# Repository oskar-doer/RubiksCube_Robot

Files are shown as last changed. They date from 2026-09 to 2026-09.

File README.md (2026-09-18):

# Rubik's Cube Robot

This robot solves a Rubik's Cube automatically. An ESP32-S3 reads the state of
a QiYi QYSC-S Rubiks Cube via Bluetooth and calculates a solution using the min2phase
algorithm. A FYSETC F6 then controls six stepper motors that turn the cube.

## Demo

Current record: **0.902 s**

<div align="center">

https://github.com/user-attachments/assets/f63d3622-d1c3-4cb1-b660-a3a5f470cd66

</div>

## Features

- Cube state detection via Bluetooth
- Solution calculation directly on the ESP32-S3
- Six individually controlled NEMA 17 stepper motors
- Parallel movement of opposite cube faces
- Status, progress, and time display on an LCD1602
- Ability to abort an ongoing movement
- Individual tests for motors, TMC UART, and the connection between both controllers

## How It Works

1. The ESP32-S3 connects to the QiYi cube via Bluetooth.
2. The current cube state is read and verified.
3. The min2phase solver calculates and evaluates suitable move sequences.
4. The ESP32 sends the selected move sequence to the FYSETC F6 via UART.
5. The F6 generates the STEP/DIR signals for the six TMC2209 motor drivers.
6. After the movement, the ESP32 verifies the cube's new state.

## Hardware

The build consists of an ESP32-S3, a FYSETC F6, six TMC2209 motor drivers,
six NEMA 17 stepper motors, an LCD1602, and a QiYi QYSC-S. The complete list is
available in the [component list](docs/HARDWARE.md).

| Robot | Control electronics |
|:---:|:---:|
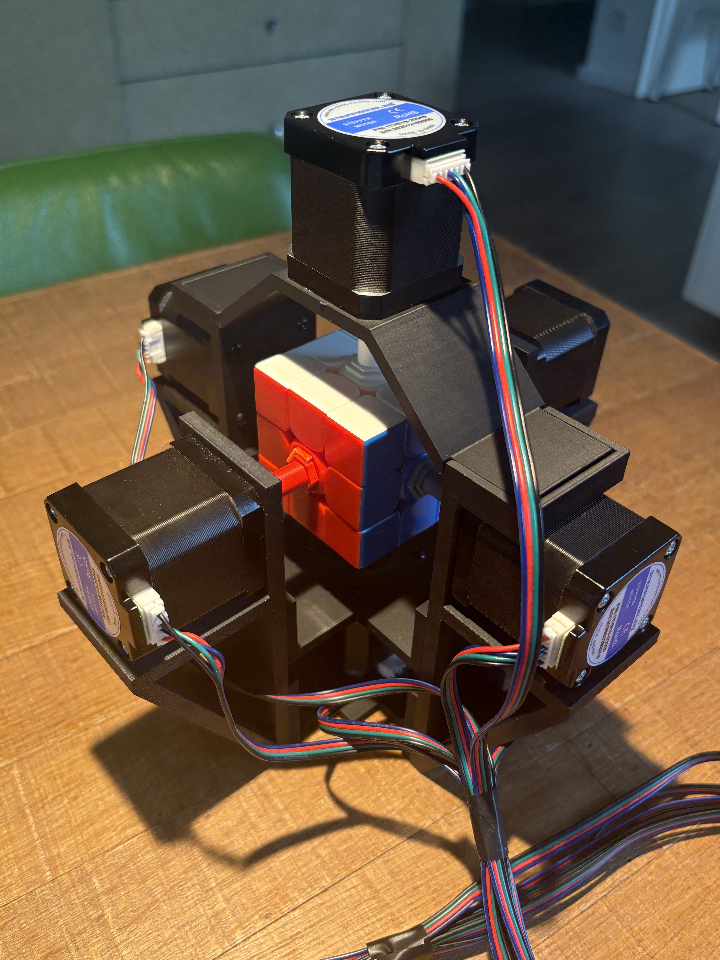
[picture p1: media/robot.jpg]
Mechanical structure of the robot
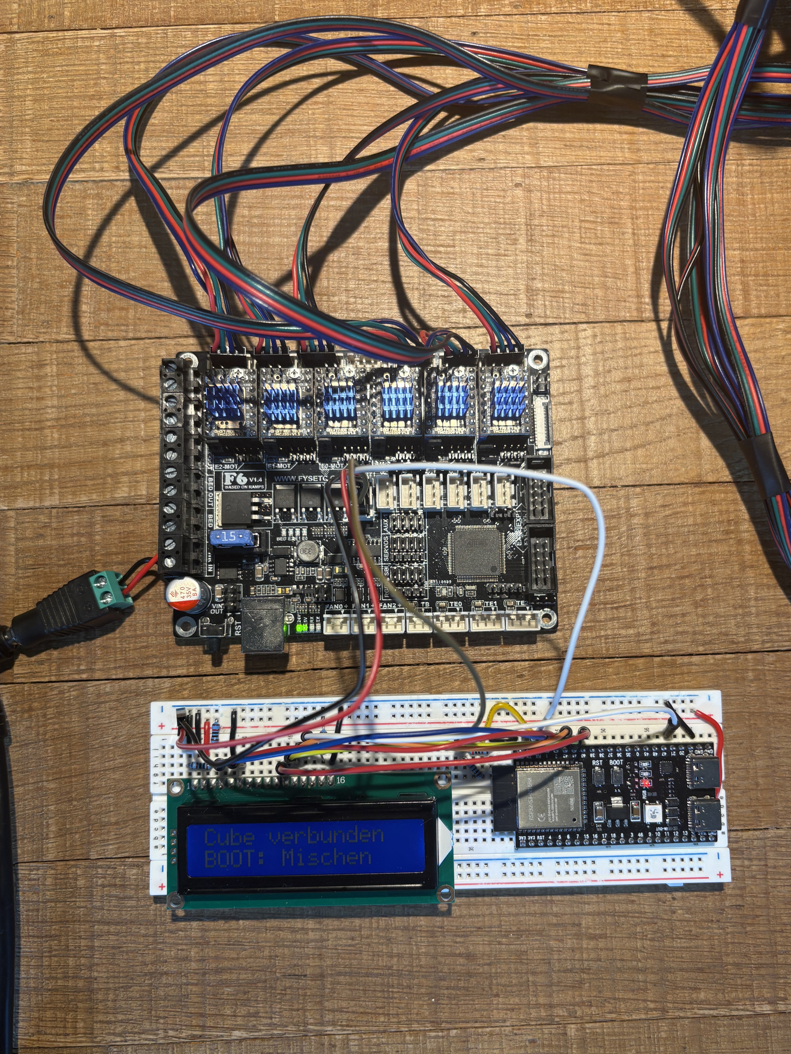
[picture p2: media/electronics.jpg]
FYSETC F6, ESP32-S3, and LCD1602
|  |  |

## Software

The firmware consists of two programs:

- [`esp32_cube_controller`](Code/robot/esp32_cube_controller/): Bluetooth,
  state verification, solver, LCD, and communication with the F6
- [`f6_motion_controller`](Code/robot/f6_motion_controller/): motor driver
  configuration and execution of the calculated cube moves

The complete connections are described in the
[wiring instructions](Code/robot/WIRING.md). Operation and configured motion
values are covered by the [robot documentation](Code/robot/README.md).

## Building the Robot

1. Print the parts in [`3D Model`](3D%20Model/).
2. Mechanically assemble the motors, adapters, frame, and cube.
3. Connect the ESP32-S3, LCD1602, FYSETC F6, and motor drivers according to the
   [wiring instructions](Code/robot/WIRING.md).
4. First, test the individual components with the programs in
   [`Code/tests`](Code/tests/).
5. Then upload the two programs in [`Code/robot`](Code/robot/).

The Arduino settings and upload instructions are provided in the README files
of the respective firmware directories.

## Tests

[`Code/tests`](Code/tests/) contains separate programs for:

- the UART connection to a TMC2209
- moving a single motor
- the UART connection between the ESP32-S3 and FYSETC F6
- checking the direction of rotation of all six motors

## Project Structure

```text
Code/
  robot/    Production firmware for ESP32-S3 and FYSETC F6
  tests/    Programs for commissioning and troubleshooting
docs/       Component list
3D Model/   Print-ready STL files
```

## Notes

- Only connect or disconnect motors and motor drivers when the 24 V supply is
  switched off.
- Check the driver orientation and current limit before switching on the power.
- The F6's 5 V TX output may only be connected to the ESP32's 3.3 V RX input
  through the [documented voltage divider](Code/robot/WIRING.md#esp32-s3-to-fysetc-f6).
- License notices for the solver and QiYi protocol are included with the
  ESP32 firmware.

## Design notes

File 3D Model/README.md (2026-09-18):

# 3D-Printed Parts

All STL files in this directory are original parts designed and created by the author of this project. They are not derived from third-party CAD models.

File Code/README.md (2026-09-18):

# Rubik's Cube Robot

This repository separates the production robot firmware from standalone
hardware tests:

```text
robot/
  esp32_cube_controller/   Production ESP32-S3 firmware
  f6_motion_controller/    Production FYSETC F6 firmware
tests/                     Individual tests for setup and troubleshooting
```

For normal operation, upload these two sketches:

- `robot/esp32_cube_controller/esp32_cube_controller.ino`
- `robot/f6_motion_controller/f6_motion_controller.ino`

The production UART connection between the ESP and F6 uses 250000 baud. The
USB monitors use 115200 baud. Sketches under `tests/` are independent diagnostic
programs and can therefore use different settings, particularly 115200 baud
between the test devices.

The complete production wiring is documented in
[`robot/WIRING.md`](robot/WIRING.md). Operation and the currently configured
motion values are documented in [`robot/README.md`](robot/README.md). Details
about the two controllers are provided in their respective subdirectories.

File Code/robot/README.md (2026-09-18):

# Rubik's Cube Robot Control

## Programs

- `esp32_cube_controller`: reads the QiYi cube via Bluetooth, calculates a
  solution with min2phase, displays the state on the LCD, and sends the move
  sequence to the F6 via UART.
- `f6_motion_controller`: receives the move sequence, generates STEP/DIR signals
  for the six TMC2209 drivers, and reports progress and measured movement time.

The F6 executes directly consecutive moves of opposite faces in parallel: U
with D, R with L, and F with B. The remaining sequence stays unchanged.

The motor assignment, direction of rotation, and steps per 90 degrees have been
verified. Motor movement is enabled in the F6 program with
`MOTION_CONFIGURATION_CONFIRMED=true`.

The complete connections for the power supply, LCD, controllers, motor drivers,
and motors are documented in [WIRING.md](WIRING.md).

## Operation

After a valid cube connection, the LCD displays `Cube verbunden` ("Cube
connected"). Briefly
pressing the ESP's BOOT button (GPIO0) solves a scrambled cube. If the Bluetooth
cube is already solved, the same button starts a random 20-move scramble.
Pressing it again during the motor run aborts the movement. The serial command
`s` starts the same state-dependent action; `x` aborts it.
As soon as the F6 reports `START`, the LCD shows the elapsed time and move
progress. After `DONE`, the ESP confirms success exclusively based on the state
subsequently reported by the Bluetooth cube. `x` aborts an ongoing motor
sequence.

After a confirmed solution, the LCD displays the motor time alone and the move
count. The USB monitor additionally shows the solver, motor, and total times.
The solver keeps the first result as a fallback and continues searching for a
total of three seconds for the fastest sequence with no more than 30 moves.
Directly consecutive moves of opposite faces count together as one time step
that can be executed in parallel.

The BOOT button may only be pressed after power-up or reset. If it is held
during a reset, the ESP starts in download mode. The RST button remains the
reset button.

## Measured Motion Values

- Reference measurement at 16 microsteps: 400 pulses produce approximately 45 degrees.
- Reference measurement at 16 microsteps: 800 pulses therefore produce 90 degrees.
- In the production profile with 2 microsteps, 100 pulses therefore correspond
  to a 90-degree turn.
- `+`, or DIR HIGH, turns counterclockwise when looking at the motor from the
  front. This means viewing it from the shaft/adapter side.
- Because the shaft/adapter side faces the cube, DIR HIGH corresponds to a
  clockwise move when looking at the respective colored cube face from the outside.

## Setting Speed and Motor Current

The clearly visible settings are at the beginning of
`f6_motion_controller.ino` in the `EINFACHE BEWEGUNGSEINSTELLUNGEN` ("simple
motion settings") block:

- `STEPS_PER_90_DEGREES = 100`: pulses for 90 degrees at 2 microsteps
- `START_SPEED_DEG_PER_SEC = 500`: speed at the beginning/end of a turn
- `MAX_SPEED_DEG_PER_SEC = 2400`: peak speed for 90-degree moves
- `MAX_SPEED_180_DEG_PER_SEC = 2600`: peak speed for 180-degree moves
- `ACCELERATION_STEPS = 8`: ramp for 90-degree moves
- `ACCELERATION_180_STEPS = 14`: longer ramp for 180-degree moves
- `MOTOR_RMS_CURRENT_MA = 1700`: running current per motor; 1700 corresponds to 1.7 A RMS
- `MOTOR_HOLD_MULTIPLIER = 0.35`: holding current for stationary motors
- `DRIVER_MICROSTEPS = 2`: microsteps configured via UART with interpolation
- `USE_SPREADCYCLE = true`: more torque during fast movements

The STEP pulses are generated by Timer1 at absolute times. As a result, serial
responses and emergency-stop polling do not change the motor speed. Opposite
faces continue to move simultaneously; individual speeds for each motor are
intentionally not used.

At startup, the F6 configures all six TMC2209 drivers via UART and checks
`test_connection = 0` and `VERSION = 0x21` for each one. If any driver does not
respond, all motor commands remain disabled and the ESP receives `DRIVER_UART`.

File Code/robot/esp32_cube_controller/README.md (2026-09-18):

# ESP32-S3 Cube Controller

This is the robot's production ESP32-S3 firmware. It connects to the QiYi
QYSC-S via Bluetooth, reads and verifies the cube state, calculates a solution,
displays the process on the LCD1602, and sends the move sequence to the FYSETC
F6 via UART.

## Uploading with the Arduino IDE

Keep the entire directory together and open `esp32_cube_controller.ino` in the
Arduino IDE.

Settings used:

| Setting | Value |
|---|---|
| Board package | esp32 by Espressif Systems 3.3.11 |
| Board | ESP32S3 Dev Module |
| CPU Frequency | 240 MHz |
| Flash Size | 16 MB (128 Mb) |
| PSRAM | OPI PSRAM |
| USB CDC On Boot | Enabled when using the native USB connector |
| USB Mode | Hardware CDC and JTAG |
| Partition Scheme | Custom (`partitions.csv`) |
| Serial monitor | 115200 baud |

When using the UART USB connector, `USB CDC On Boot` must be disabled. If the
upload does not start, hold BOOT, briefly press RESET, release BOOT, and upload
again.

On the first startup, min2phase generates its search tables in PSRAM and saves
them to LittleFS. This can take several minutes. Later startups load the
appropriate cache from flash memory.

## Wiring

The LCD1602 pinout, ESP-to-F6 UART connection, voltage divider, power wiring,
driver setup, and motor connections are documented centrally in
[WIRING.md](../WIRING.md).

## Operation

- Briefly press BOOT: solve a scrambled cube; scramble a solved cube with 20 moves
- Hold BOOT for three seconds: calibrate a physically solved cube as solved
- Press BOOT during a motor run: send an emergency stop to the F6

| Serial command | Function |
|---|---|
| `s` | Solve or scramble depending on the cube state |
| `c` | Calibrate a solved cube |
| `x` | Abort the motor run |
| `p` | Display the cube state and battery level |
| `t` | Test the solver with a virtual test cube |
| `l` | Display an LCD test pattern |
| `w` | Measure the LCD lines individually |
| `r` | Reestablish the Bluetooth connection |
| `h` or `?` | Display help |

The solver runs in a separate task so that Bluetooth and the display continue
to operate during the search. The cube must not be turned during the
calculation; any solution rendered outdated as a result is discarded.

## Solution Selection

The first valid solution is retained as a fallback. The ESP then continues
searching for a total of three seconds and evaluates every variant found by the
number of motor time steps:

- A normal move counts as one time step.
- Consecutive moves of opposite faces (`U D`, `R L`, `F B`, and vice versa)
  count together as one time step because the F6 executes them simultaneously.
- If the number of time steps is equal, the sequence with fewer individual moves wins.

The selected sequence may contain no more than 30 individual moves. Each answer
is replayed using an independent cube model before it is sent to the F6. The
evaluation selects the best variant found within the search window; it does not
prove a global optimum.

## Feedback and Errors

During the motor run, the LCD shows progress and elapsed time. After the run,
the ESP verifies the new Bluetooth state. Even if the solution fails, the motor
time reported by the F6 remains visible. On success, the LCD displays the motor
time and move count; the USB monitor outputs the solver, motor, and total times.

- `F6 nicht bereit` ("F6 not ready"): check the UART connection, common ground, and both baud rates.
- `TMC-UART Fehler` ("TMC UART error"): check the drivers named on the LCD and their jumpers.
- `PSRAM 0 MB`: check OPI PSRAM, the board selection, and the N16R8 module.
- No cube: wake the cube and disconnect it from other apps.
- Invalid state: calibrate the cube in the manufacturer's app or use `c` here.

## File Structure

- `esp32_cube_controller.ino`: Arduino entry point
- `app.cpp`: Bluetooth, LCD, operation, and F6 communication
- `qiyi_protocol.h`: QiYi frames, CRC, and state decoding
- `solver_adapter.cpp/.h`: min2phase integration and preparation
- `cube_model.c/.h`: independent state and solution verification
- `src/min2phase/`: adapted solver library

## Sources and Licenses

- [min2phaseCXX](https://github.com/lilborgo/min2phaseCXX): `src/min2phase/UPSTREAM-LICENSE.md`
- [QiYi protocol documentation](https://codeberg.org/Flying-Toast/qiyi_smartcube_protocol) by Simon Schwartz (MIT): `LICENSE-qiyi.txt`
- Independent cube model and integration software (GPL-3.0-or-later): `LICENSE-GPL-3.0.txt`

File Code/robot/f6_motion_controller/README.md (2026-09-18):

# F6 Motion Controller

Arduino board profile: `FYSETC F6 V1.4`, library: `TMCStepper`, serial
monitor: 115200 baud. The UART connection to the ESP on `Serial1` operates at
250000 baud.

The controller UART, TMC2209 setup, and motor connections are documented in
[WIRING.md](../WIRING.md).

The controller understands solutions consisting of `U R F D L B` and the
suffixes `'` and `2`. Example from the ESP:

```text
RUN 1 U R' F2 D
```

Responses:

```text
READY
PONG
START 1 4
MOVE 1 1 4
DONE 1 1234
ERR 1 FEHLERNAME
```

`!` aborts a movement. You can also enter `x` in the F6's USB serial monitor
for this purpose.

Timer1 generates the STEP edges at absolute times. The motion profile uses 2
microsteps with TMC interpolation, separate ramps for 90- and 180-degree moves,
and continues to execute moves of opposite faces in parallel.

The six entries in `motors[]`, their directions of rotation, and
`MOTION_CONFIGURATION_CONFIRMED=true` correspond to the verified setup. They
only need to be changed if the motors or slots are rearranged.

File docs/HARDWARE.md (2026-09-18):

# Hardware Components

The connections between these components are documented in the
[robot wiring instructions](../Code/robot/WIRING.md).

* 1x ESP32-S3-WROOM-1-N16R8 module from Espressif Systems
* 1x F6 V1.4 control board from FYSETC
* 6x TMC2209 V1.3 motor drivers from BIGTREETECH
  * On these modules, the R10 solder bridge on the `PDN_UART` signal had to be
    closed for UART operation. Other TMC2209 StepStick variants with `PDN_UART`
    already configured or exposed appropriately may simplify the build. Before
    purchasing, verify the pin assignment and UART connection against the
    FYSETC F6 V1.4.
* Heat sinks for the TMC2209 motor drivers
* 6x 17HE19-2004S NEMA 17 stepper motors from StepperOnline
* 1x power supply, 24 V DC / 8 A
* 1x LCD1602 display module
* 1x QYSC-S Bluetooth cube from QiYi
* 1x 10 kOhm, 3x 1 kOhm, and 1x 2 kOhm resistors (0.25 W is sufficient):
  10 kOhm/1 kOhm for the LCD contrast divider, 1 kOhm for the LCD backlight,
  and 1 kOhm/2 kOhm for the F6-to-ESP UART level divider
* Small electronic components and connection cables
* M3 threaded insert and M3 screws

## Documentation

* [ESP32-S3-WROOM-1 datasheet from Espressif](https://www.espressif.com/sites/default/files/documentation/esp32-s3-wroom-1_wroom-1u_datasheet_en.pdf)
* [FYSETC F6 documentation, schematic, and board files](https://github.com/FYSETC/FYSETC-F6)
* [General TMC2209 documentation from BIGTREETECH](https://github.com/bigtreetech/docs/blob/master/docs/TMC2209.md)
* [Product information and datasheet for the StepperOnline 17HE19-2004S](https://www.omc-stepperonline.com/e-series-nema-17-bipolar-55ncm-77-88oz-in-2a-42x48mm-4-wires-w-1m-cable-connector-17he19-2004s)

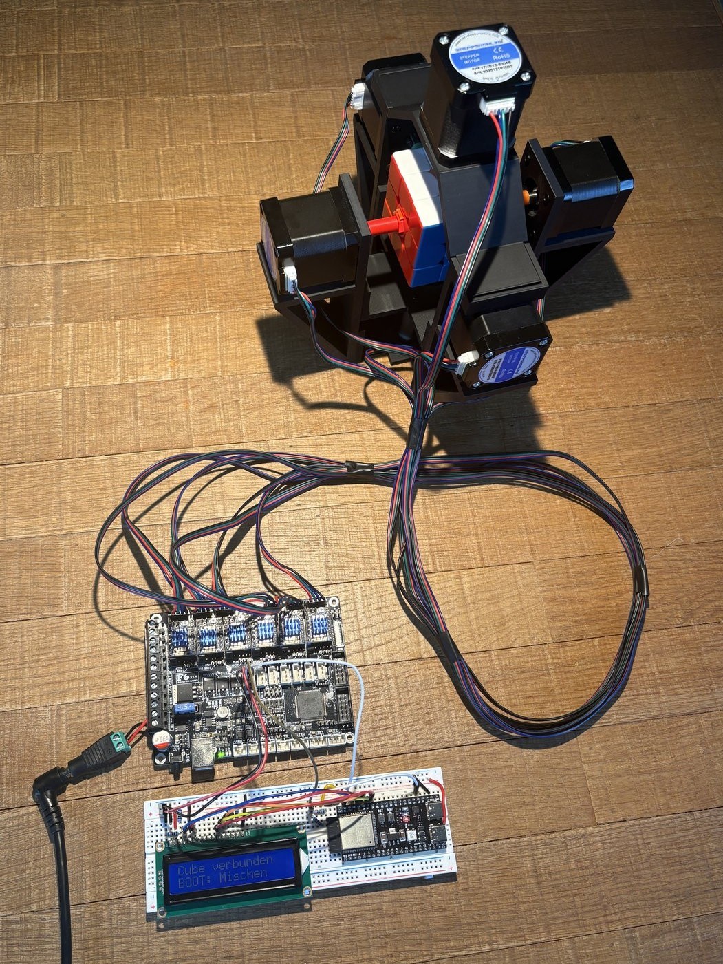
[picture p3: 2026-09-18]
media/robot-and-electronics.jpg

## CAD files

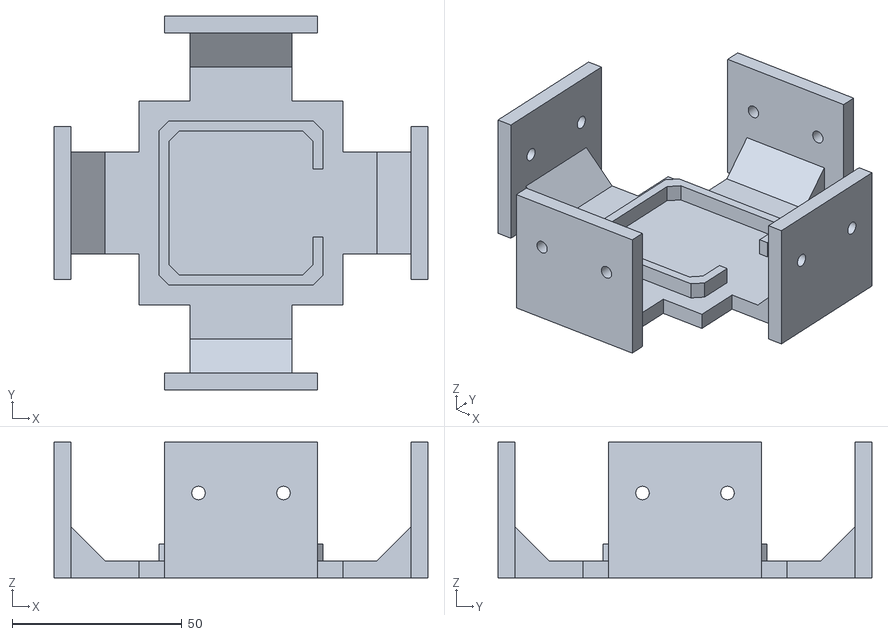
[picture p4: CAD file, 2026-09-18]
3D Model/Bodenplatte.STL
110.0 x 110.0 x 40.0

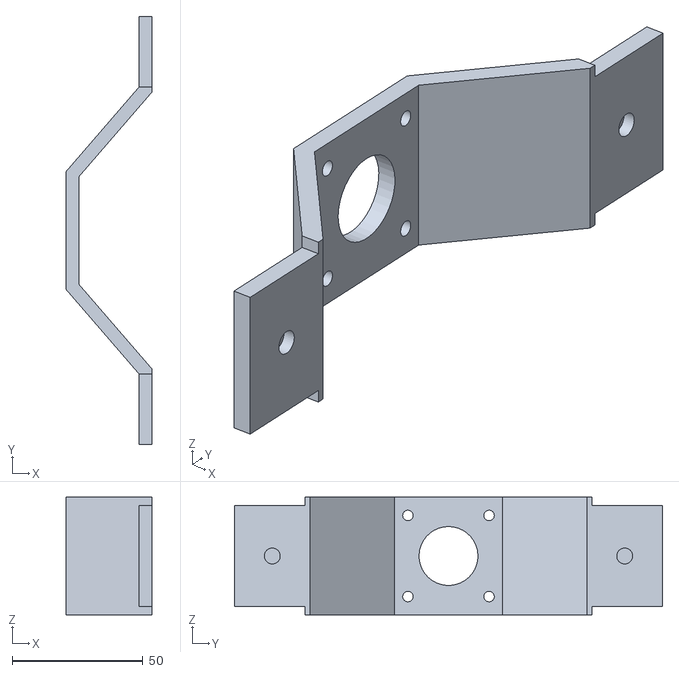
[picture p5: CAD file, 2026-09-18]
3D Model/Platte oben.STL
32.8 x 163.5 x 45.0

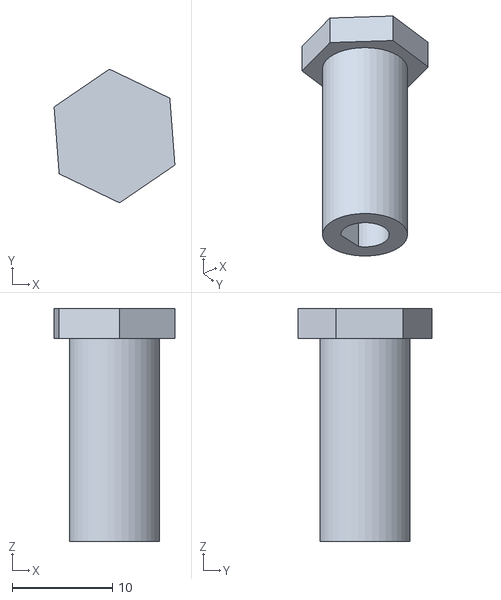
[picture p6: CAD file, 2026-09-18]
3D Model/adapter oben_unten.STL
12.1 x 13.4 x 23.3

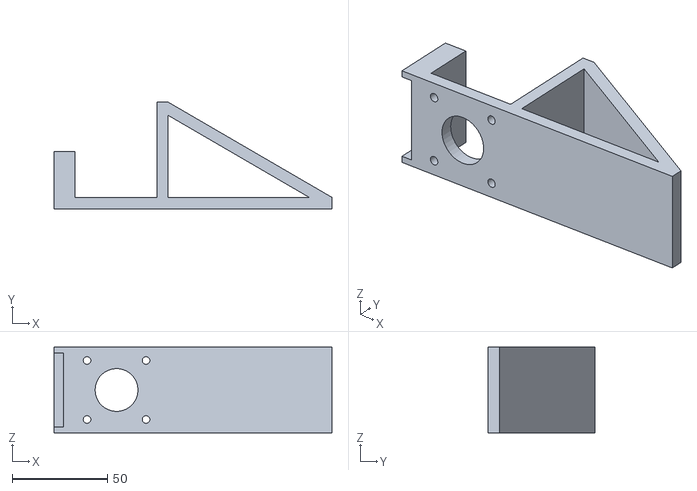
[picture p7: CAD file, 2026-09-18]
3D Model/Seiten platte - mit halter.STL
146.0 x 56.0 x 45.0

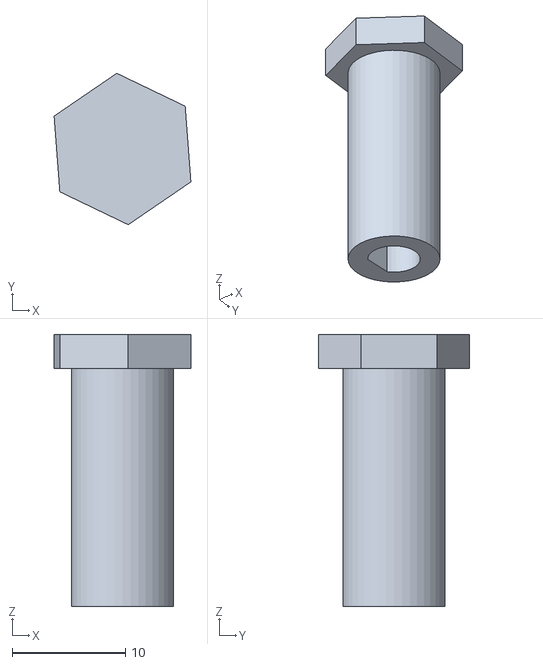
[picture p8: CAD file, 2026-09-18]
3D Model/adapter seite.STL
12.1 x 13.4 x 24.0

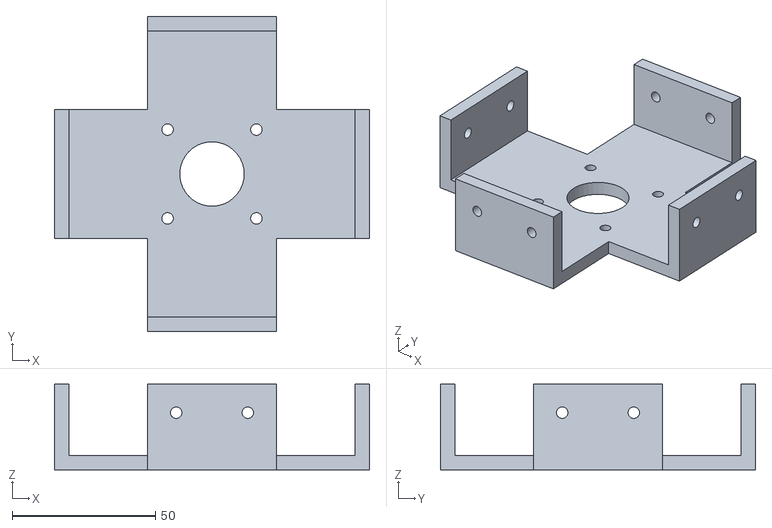
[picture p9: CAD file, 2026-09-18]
3D Model/unterer Motor halter.STL
110.0 x 110.0 x 30.0

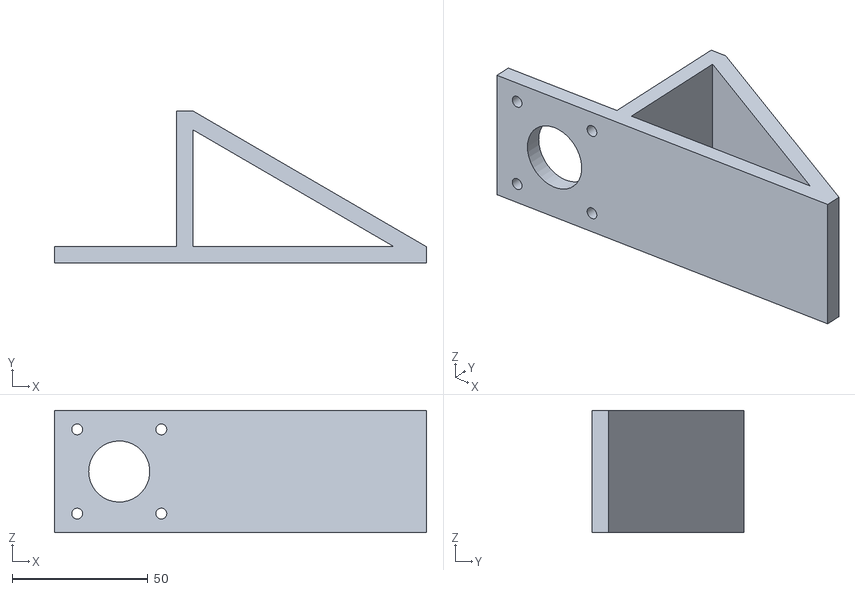
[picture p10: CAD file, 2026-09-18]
3D Model/Seiten platte.STL
137.0 x 56.0 x 45.0

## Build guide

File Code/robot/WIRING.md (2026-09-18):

# Wiring Instructions

This document contains the complete wiring for the production robot. The test
sketches under `../tests/` may use different baud rates, but they use the same
physical ESP32-S3, F6, driver, and motor connections described here.

## Safety

- Switch off and disconnect the 24 V supply before installing or removing a
  TMC2209 driver or motor cable.
- Check the polarity of every supply connection before switching on power.
- Never connect the F6's 24 V motor supply to the ESP32-S3 or LCD.
- Connect the ESP32-S3 and LCD only to the F6's regulated 5 V output, never to
  its 24 V input.
- Fit a heat sink to every TMC2209 and check each driver's orientation before
  powering the F6.
- The F6 and ESP32-S3 must share GND.
- The F6 TX1 signal is 5 V. Connect it to the ESP32-S3 only through the voltage
  divider shown below.

## Power

1. Connect the 24 V DC / 8 A supply to the main power input of the FYSETC F6,
   observing the marked positive and negative terminals.
2. Connect a regulated `5V` output on the F6 directly to the ESP32-S3's
   `5V`/`5Vin` input. Connect F6 GND directly to ESP32-S3 GND.
3. Connect the same F6 `5V` rail directly to LCD pin 2 (`VDD`) and the F6 GND
   rail directly to LCD pin 1 (`VSS`). For the contrast voltage, connect a
   10 kOhm resistor from F6 `5V` to LCD pin 3 (`VO`) and a 1 kOhm resistor from
   LCD pin 3 (`VO`) to F6 GND. The LCD is not powered through the ESP.
4. Connect LCD pin 15 (`A`/`LED+`) to F6 `5V` through a 1 kOhm resistor and
   connect LCD pin 16 (`K`/`LED-`) directly to F6 GND.
5. The UART connection uses this same common GND.

The ESP32-S3 and LCD are two parallel loads on the F6's 5 V rail: both receive
their 5 V directly from the F6. Do not feed either device from the F6's 24 V
input. When connecting USB to the ESP32-S3 for programming, avoid connecting
two 5 V sources unless the specific ESP32-S3 development board explicitly
supports it.

Do not switch on the 24 V supply until the drivers, motor cables, controller
UART, and common ground have all been checked.

## ESP32-S3 to LCD1602

The LCD is connected directly in 4-bit mode. These GPIO numbers match the
`LiquidCrystal` configuration in `esp32_cube_controller/app.cpp`.

| LCD1602 pin | Function | Connection |
|---|---|---|
| 1 | VSS | F6 GND |
| 2 | VDD | F6 5V |
| 3 | VO, contrast | Junction of a 10 kOhm / 1 kOhm voltage divider (see below) |
| 4 | RS | GPIO1 |
| 5 | RW | GND |
| 6 | E | GPIO2 |
| 7-10 | D0-D3 | not connected |
| 11 | D4 | GPIO40 |
| 12 | D5 | GPIO41 |
| 13 | D6 | GPIO42 |
| 14 | D7 | GPIO21 |
| 15 | A / LED+ | F6 5V through a 1 kOhm resistor |
| 16 | K / LED- | F6 GND |

Wire the two fixed contrast resistors as a voltage divider:

```text
F6 5V ---- R1: 10 kOhm ----+---- LCD pin 3 (VO)
                            |
                         R2: 1 kOhm
                            |
F6 GND ---------------------+
```

R1 is the upper resistor between `5V` and `VO`; R2 is the lower resistor
between `VO` and GND. With a 5 V supply, this produces approximately 0.45 V at
LCD pin 3 (`5 V * 1 kOhm / (10 kOhm + 1 kOhm)`), which provides a suitable
fixed contrast voltage for a typical LCD1602. Both resistors are ordinary
low-power types; 0.25 W is more than sufficient.

The 1 kOhm resistor between F6 `5V` and LCD pin 15 limits the backlight current.

## ESP32-S3 to FYSETC F6

| ESP32-S3 | FYSETC F6 V1.4 |
|---|---|
| 5V/5Vin | 5V |
| TX / GPIO43 | D19 / RX1 |
| RX / GPIO44 | D18 / TX1 through the voltage divider below |
| GND | GND |

ESP TX supplies 3.3 V and can be connected directly to F6 RX1. F6 TX1 supplies
5 V and must be reduced before it reaches the ESP RX input:

```text
F6 D18/TX1 -- 1 kOhm --+-- ESP RX/GPIO44
                       |
                     2 kOhm
                       |
                      GND
```

The junction between the 1 kOhm and 2 kOhm resistors connects to ESP GPIO44.
The lower end of the 2 kOhm resistor connects to the same common GND as both
controllers.

The production firmware communicates at 250000 baud. The USB serial monitors
remain at 115200 baud. After changing the controller baud rate, upload matching
firmware to both controllers.

## TMC2209 Drivers on the F6

Install one TMC2209 in each of the `X`, `Y`, `Z`, `E0`, `E1`, and `E2` driver
slots. The production firmware uses the F6's onboard STEP, DIR, ENABLE, and UART
connections, so no separate signal wires are required between the F6 and these
six drivers.

For the BIGTREETECH TMC2209 V1.3 modules used in this build:

- close the `R10` solder bridge on each module for UART operation;
- set `JP1` for each F6 driver slot to pins 2-3;
- remove the `MS1` and `MS2` jumpers so the UART address is 0;
- verify the module orientation against the F6 pin labels before applying
  power; and
- install a heat sink on every driver.

At startup, the F6 checks all six UART connections. The robot remains disabled
if a driver does not respond with `test_connection = 0` and `VERSION = 0x21`.

## Motors to the F6

Connect each motor to the output belonging to its assigned driver slot:

| Cube face | Color/position | F6 driver slot | F6 motor output |
|---|---|---|---|
| U | white, top | E1 | E1-MOT |
| R | red, right | Y | Y-MOT |
| F | green, front | E0 | E0-MOT |
| D | yellow, bottom | E2 | E2-MOT |
| L | orange, left | X | X-MOT |
| B | blue, back | Z | Z1-MOT |

`Z1-MOT` and `Z2-MOT` are two motor sockets connected in series to the same Z
driver; they are not independent axes. This build uses `Z1-MOT` for the B motor.
If only one Z socket is occupied, bridge the unused Z motor socket appropriately
for the series circuit.

Keep each motor's two coil pairs together in the four-pin connector. If a cable
has been repinned or replaced, verify the coil pairs with the motor datasheet or
an ohmmeter before connecting it.

## Final Check Before Power-Up

- The 24 V polarity at the F6 is correct.
- Every driver is oriented correctly, has its required UART configuration, and
  has a heat sink.
- All six motor cables are in the outputs listed above.
- ESP `5V`/`5Vin` and LCD `VDD` are both connected directly to F6 `5V`.
- The LCD is not powered from the ESP32-S3.
- LCD pin 3 is connected to the junction of the fixed contrast divider: 10 kOhm
  to F6 `5V` and 1 kOhm to F6 GND.
- LCD pin 15 (`A`/`LED+`) is connected to F6 `5V` through a 1 kOhm resistor,
  and LCD pin 16 (`K`/`LED-`) is connected directly to F6 GND.
- LCD pins 7-10 are left unconnected and LCD RW is tied to GND.
- ESP GPIO43 goes directly to F6 D19/RX1.
- F6 D18/TX1 reaches ESP GPIO44 only through the 1 kOhm/2 kOhm divider.
- ESP GND, LCD GND, voltage-divider GND, and F6 GND are common.

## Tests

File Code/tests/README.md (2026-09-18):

# Standalone Tests

The sketches in this directory are intended for setup and troubleshooting. They
are not part of the production robot firmware and are uploaded in place of the
normal ESP or F6 program.

| Directory | Purpose |
|---|---|
| `tmc_uart_test` | Test the UART connection to a single TMC2209 |
| `tmc_motor_test` | Slowly move a single F6 motor slot |
| `esp_f6_motor_uart_test` | ESP side of the combined UART/direction test |
| `f6_esp_motor_uart_test` | F6 side of the combined UART/direction test |

Each test uses the settings from its own README or sketch. In particular, the
UART test pair operates at 115200 baud, while the production programs under
`robot/` communicate at 250000 baud.

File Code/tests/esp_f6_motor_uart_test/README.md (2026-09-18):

# ESP-F6 UART and Motor Direction Test

Upload `esp_f6_motor_uart_test.ino` to the ESP32-S3. Upload the
`../f6_esp_motor_uart_test/f6_esp_motor_uart_test.ino` sketch to the FYSETC F6.
Both serial interfaces operate at 115200 baud.

This applies only to this matching test pair. The production sketches under
`robot/` communicate at 250000 baud.

## Arduino IDE Settings for the ESP32-S3 N16R8

| Tools menu item | Setting |
|---|---|
| Board | ESP32S3 Dev Module |
| USB Mode | Hardware CDC and JTAG |
| USB CDC On Boot | Enabled |
| Upload Mode | UART0 / Hardware CDC |
| CPU Frequency | 240 MHz |
| Flash Size | 16 MB (128 Mb) |
| PSRAM | OPI PSRAM |
| Partition Scheme | Default 4MB with spiffs |
| Upload Speed | 921600; 460800 if problems occur |
| Core Debug Level | None |
| Erase All Flash Before Sketch Upload | Disabled |
| Port | COM port of the ESP's native USB connector |

For this test, plug the USB cable into the ESP's native connector, which is
usually labeled `USB`. This keeps GPIO43/TX and GPIO44/RX available for the
UART connection to the F6. For the solver later on, select `Partition Scheme:
Custom` again because it requires the included `partitions.csv`.

First, send `p` in the ESP serial monitor without the 24 V motor supply. The
response `F6 > ESP: PONG` confirms TX, RX, and GND in both directions.

With the 24 V motor supply switched on, a command such as `u+` slowly moves the
assigned motor by 400 pulses. `u-` moves the same motor in the opposite
direction. The symbols represent the electrical DIR direction and are recorded
as clockwise or counterclockwise after the test.

Always determine the direction of rotation by looking directly at the tested
cube face from the outside. To turn it back, send the same letter with the
opposite sign.

| Command | Motor |
|---|---|
| `u+`, `u-` | U, white, E1 |
| `r+`, `r-` | R, red, Y |
| `f+`, `f-` | F, green, E0 |
| `d+`, `d-` | D, yellow, E2 |
| `l+`, `l-` | L, orange, X |
| `b+`, `b-` | B, blue, Z1 |
| `p` | UART ping without movement |
| `x` | Abort movement |

A custom pulse count is possible, for example `u+ 200`. Values from 1 to 5000
pulses are allowed. Drivers are disabled at startup and after each test.

## Measurement Result

- `u+`, `r+`, `f+`, `d+`, `l+`, and `b+`: approximately 45 degrees at 400 pulses each.
- All `+` directions: counterclockwise when viewed from the front of the motor.
- This results in 800 pulses per quarter turn.

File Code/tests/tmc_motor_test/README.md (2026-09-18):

# Single-Motor Test for All F6 Slots

This test controls a selected TMC2209 driver channel on the FYSETC F6 V1.4.

## Selecting a Slot

Set `DRIVER_SLOT` at the very top of the sketch, for example:

- `#define DRIVER_SLOT SLOT_X`
- `#define DRIVER_SLOT SLOT_Y`
- `#define DRIVER_SLOT SLOT_Z`
- `#define DRIVER_SLOT SLOT_E0`
- `#define DRIVER_SLOT SLOT_E1`
- `#define DRIVER_SLOT SLOT_E2`

## Pin Assignment

- X: STEP 54, DIR 55, ENABLE 38
- Y: STEP 60, DIR 61, ENABLE 56
- Z: STEP 43, DIR 48, ENABLE 58
- E0: STEP 26, DIR 28, ENABLE 24
- E1: STEP 36, DIR 34, ENABLE 30
- E2: STEP 59, DIR 57, ENABLE 40
- ENABLE is active LOW

The board has six TMC slots: X, Y, Z, E0, E1, and E2. Z1-MOT and Z2-MOT are
two motor sockets connected in series to the same Z driver. They therefore
cannot be controlled separately. If only one Z motor is connected, the other
Z-MOT socket must be bridged appropriately.
- Serial interface: 115200 baud

## Operation

The driver is disabled after startup or reset. The following commands are available in the serial monitor:

- `f`: slow forward test movement
- `r`: slow reverse test movement

Each command generates 400 slow step pulses and then disables the driver again.

## Procedure for the First Test

1. Switch off and disconnect the 24 V supply.
2. Check the driver orientation, jumpers, and current limit.
3. Connect the motor without a mechanical load and use the TMC2209 with a heat sink.
4. Upload the sketch to the FYSETC F6 V1.4.
5. Open the serial monitor at 115200 baud.
6. Switch on the 24 V supply.
7. Send `f` first, followed by `r` if needed.
8. Switch off immediately if there are unusual noises, vibrations, or excessive heat.

## Safety

- Only connect or disconnect the TMC2209 and motor when the 24 V supply is switched off.
- Check the driver orientation and current limit before the first run.
- Perform the first test without a mechanical load and with a heat sink.

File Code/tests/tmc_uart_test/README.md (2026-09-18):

# TMC2209 UART Test for All F6 Slots

This test reads the TMC2209 in a selected driver slot on the FYSETC F6 V1.4.
A successful response confirms the UART signal path through the F6 jumper and
the closed R10 bridge on the BTT driver.

## Selecting a Slot

Set `DRIVER_SLOT` at the very top of the sketch, for example:

- `#define DRIVER_SLOT SLOT_X`
- `#define DRIVER_SLOT SLOT_Y`
- `#define DRIVER_SLOT SLOT_Z`
- `#define DRIVER_SLOT SLOT_E0`
- `#define DRIVER_SLOT SLOT_E1`
- `#define DRIVER_SLOT SLOT_E2`

The board has six TMC slots: X, Y, Z, E0, E1, and E2. The two labels Z1-MOT
and Z2-MOT refer to the two motor sockets on the same Z TMC slot. A UART test
can therefore only test the shared Z TMC.

## Requirements

- Board profile `FYSETC F6 V1.4`
- `TMCStepper` library
- JP1 on the selected F6 slot set to pins 2-3
- R10 closed on the BTT TMC2209 V1.3
- MS1/MS2 jumpers removed, resulting in UART address 0
- 24 V main power supply switched on

The enable output remains HIGH during the test. The motor is therefore not
driven.

The serial monitor and the UART connection to the TMC2209 both operate at
115200 baud.

## Expected Output on Success

```text
test_connection = 0
VERSION = 0x21
ERGEBNIS: UART OK - TMC2209 antwortet.
```

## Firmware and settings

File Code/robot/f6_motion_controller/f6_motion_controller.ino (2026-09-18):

#include <Arduino.h>
#include <TMCStepper.h>
#include <avr/interrupt.h>

static const char BUILD_TAG[]="ROBOT-F6-2026-09-17-1";

// FYSETC F6 V1.4: Kommunikation mit dem ESP32-S3 ueber Serial1.
// F6 D19/RX1 empfaengt vom ESP TX/GPIO43.
// F6 D18/TX1 sendet ueber einen 5-V->3,3-V-Spannungsteiler an ESP RX/GPIO44.
static constexpr uint32_t PC_BAUD=115200;
static constexpr uint32_t ESP_BAUD=250000;
static constexpr bool MOTION_DEBUG=false;

// ============================================================================
// EINFACHE BEWEGUNGSEINSTELLUNGEN
// ============================================================================
// Bei 2 Mikroschritten benoetigen die 1,8-Grad-Motoren 100 Impulse fuer 90 Grad.
// Die TMC-Interpolation bleibt aktiv und glaettet intern auf 256 Mikroschritte.
static constexpr uint16_t STEPS_PER_90_DEGREES=100;

// Zwischenprofil zum schrittweisen Herantasten an etwa drei Sekunden reine
// Motorzeit. 2400 Grad/s entsprechen etwa 400 Motor-Umdrehungen/min.
static constexpr uint16_t START_SPEED_DEG_PER_SEC=500;
static constexpr uint16_t MAX_SPEED_DEG_PER_SEC=2400;
// 180-Grad-Zuege haben eine laengere Beschleunigungsstrecke und duerfen deshalb
// eine etwas hoehere Spitzengeschwindigkeit erreichen.
static constexpr uint16_t MAX_SPEED_180_DEG_PER_SEC=2600;

// Anzahl der Impulse zum Beschleunigen und Abbremsen.
// Groesser = weichere, laengere Rampe; kleiner = haertere Beschleunigung.
static constexpr uint16_t ACCELERATION_STEPS=8;
static constexpr uint16_t ACCELERATION_180_STEPS=14;

// Der Scramble benutzt dieses feste Tempo ohne Beschleunigungsrampe. Dieser
// Wert ist unabhaengig von START_SPEED und MAX_SPEED des Loesevorgangs.
static constexpr uint16_t SCRAMBLE_SPEED_DEG_PER_SEC=300;

// Laufstrom pro Motor in Milliampere RMS. 1700 bedeutet 1,7 A RMS.
// Dieser Wert wird beim Start per TMC-UART an alle sechs Treiber geschrieben.
static constexpr uint16_t MOTOR_RMS_CURRENT_MA=1700;

// Nicht drehende Motoren halten mit 35 % des Laufstroms ihre Cube-Seite fest.
static constexpr float MOTOR_HOLD_MULTIPLIER=0.35F;

// Mikroschritte werden ebenfalls per UART gesetzt. Der Test ergab bei 16
// Mikroschritten 800 Impulse pro 90 Grad; bei 2 sind es entsprechend 100.
static constexpr uint16_t DRIVER_MICROSTEPS=2;

// true = SpreadCycle fuer mehr Drehmoment bei schnellen Bewegungen;
// false = StealthChop fuer leiseren Lauf.
static constexpr bool USE_SPREADCYCLE=true;

static constexpr float DRIVER_R_SENSE=0.110F;
static constexpr uint8_t DRIVER_ADDRESS=0b00;

// Software-UART kann bei einer einzelnen Abfrage gelegentlich ein Byte
// verpassen. Deshalb wird ein Treiber erst nach mehreren Fehlversuchen als
// nicht erreichbar gemeldet.
static constexpr uint8_t DRIVER_UART_ATTEMPTS=5;
static constexpr uint16_t DRIVER_UART_RETRY_DELAY_MS=40;

// Getrennte, bereits getestete TMC-UART-Leitungen des F6.
static TMC2209Stepper tmcX (72,71,DRIVER_R_SENSE,DRIVER_ADDRESS);
static TMC2209Stepper tmcY (73,78,DRIVER_R_SENSE,DRIVER_ADDRESS);
static TMC2209Stepper tmcZ (75,79,DRIVER_R_SENSE,DRIVER_ADDRESS);
static TMC2209Stepper tmcE0(77,81,DRIVER_R_SENSE,DRIVER_ADDRESS);
static TMC2209Stepper tmcE1(76,80,DRIVER_R_SENSE,DRIVER_ADDRESS);
static TMC2209Stepper tmcE2(62,82,DRIVER_R_SENSE,DRIVER_ADDRESS);

// Erst auf true setzen, nachdem Zuordnung, Drehrichtung, Mikroschritte und
// Schritte pro Vierteldrehung am aufgebauten Roboter bestaetigt wurden.
static constexpr bool MOTION_CONFIGURATION_CONFIRMED=true;

struct MotorConfig {
  char face;
  uint8_t stepPin;
  uint8_t dirPin;
  uint8_t enablePin;
  uint16_t quarterSteps;
  bool clockwiseDirHigh;
  TMC2209Stepper *driver;
};

// Bestaetigte Seiten-/Steckplatzzuordnung:
// U/weiss=E1, R/rot=Y, F/gruen=E0, D/gelb=E2, L/orange=X, B/blau=Z1.
// Gemessen wurden bei 16 Mikroschritten 800 STEP-Impulse pro 90 Grad. Der
// Produktionsbetrieb nutzt 2 Mikroschritte und deshalb 100 Impulse.
// Gemessen: DIR HIGH ('+' im Test) dreht alle Motoren gegen den Uhrzeigersinn,
// wenn auf die Wellen-/Adapterseite geschaut wird. Da diese Seite zum Cube
// zeigt, entspricht das von aussen auf die Cube-Flaeche gesehen einem
// Uhrzeigersinn-Zug. Deshalb ist clockwiseDirHigh bei allen Motoren true.
static MotorConfig motors[] = {
  {'U',36,34,30,STEPS_PER_90_DEGREES,true,&tmcE1}, // weiss, oben, E1
  {'R',60,61,56,STEPS_PER_90_DEGREES,true,&tmcY }, // rot, rechts, Y
  {'F',26,28,24,STEPS_PER_90_DEGREES,true,&tmcE0}, // gruen, vorne, E0
  {'D',59,57,40,STEPS_PER_90_DEGREES,true,&tmcE2}, // gelb, unten, E2
  {'L',54,55,38,STEPS_PER_90_DEGREES,true,&tmcX }, // orange, links, X
  {'B',43,48,58,STEPS_PER_90_DEGREES,true,&tmcZ }  // blau, hinten, Z1/Z-Treiber
};

// STEP ist pro Impuls eine halbe Periode HIGH und eine halbe Periode LOW.
static constexpr uint16_t SLOW_HALF_PERIOD_US=
  (uint16_t)(45000000UL/((uint32_t)STEPS_PER_90_DEGREES*(uint32_t)START_SPEED_DEG_PER_SEC));
static constexpr uint16_t FAST_HALF_PERIOD_US=
  (uint16_t)(45000000UL/((uint32_t)STEPS_PER_90_DEGREES*(uint32_t)MAX_SPEED_DEG_PER_SEC));
static constexpr uint16_t FAST_180_HALF_PERIOD_US=
  (uint16_t)(45000000UL/((uint32_t)STEPS_PER_90_DEGREES*(uint32_t)MAX_SPEED_180_DEG_PER_SEC));
static constexpr uint16_t SCRAMBLE_HALF_PERIOD_US=
  (uint16_t)(45000000UL/((uint32_t)STEPS_PER_90_DEGREES*(uint32_t)SCRAMBLE_SPEED_DEG_PER_SEC));
static_assert(SLOW_HALF_PERIOD_US>FAST_HALF_PERIOD_US,
              "START_SPEED muss kleiner als MAX_SPEED sein");
static_assert(SLOW_HALF_PERIOD_US>FAST_180_HALF_PERIOD_US,
              "START_SPEED muss kleiner als MAX_SPEED_180 sein");
static constexpr size_t MAX_MOVES=30;
static constexpr uint8_t DRIVER_ENABLE_DELAY_MS=10;
static constexpr uint16_t EMERGENCY_POLL_US=500;
static constexpr uint16_t TIMER1_TICKS_PER_US=(uint16_t)(F_CPU/8UL/1000000UL);
static constexpr uint16_t TIMER1_MIN_LEAD_TICKS=32;
static_assert(F_CPU==16000000UL,"Das Timerprofil erwartet das F6 mit 16 MHz");

struct ParsedMove {
  uint8_t motorIndex;
  uint8_t quarterTurns;
  bool inverse;
};

// Muss vor den ersten Funktionen stehen, damit der Arduino-.ino-Preprozessor
// die automatisch erzeugten Funktionsdeklarationen korrekt anlegen kann.
struct TimerTurn {
  MotorConfig *motor;
  volatile uint8_t *stepPort;
  uint8_t stepMask;
  uint32_t pulses;
  volatile uint32_t completedPulses;
  volatile uint16_t nextEdgeTicks;
  volatile uint16_t halfPeriodTicks;
  bool scramble;
  bool halfTurn;
  volatile bool stepHigh;
  volatile bool finished;
};

static char receiveLine[192];
static size_t receiveLength=0;
static bool abortRequested=false;
static bool running=false;
static bool driversReady=false;
static char failedDriverFaces[8]="";
static uint32_t lastDriverRetry=0;
static TimerTurn timerTurns[2];
static volatile uint8_t timerTurnCount=0;
static volatile bool timerMotionActive=false;

static bool configureDriver(MotorConfig &motor) {
  TMC2209Stepper &driver=*motor.driver;
  driver.beginSerial(115200);
  driver.begin();
  delay(30);

  uint8_t connection=0xFF;
  uint8_t version=0x00;
  uint8_t usedAttempts=0;

  for(uint8_t attempt=1;attempt<=DRIVER_UART_ATTEMPTS;++attempt) {
    usedAttempts=attempt;
    connection=driver.test_connection();
    version=driver.version();
    if(connection==0 && version==0x21) break;
    delay(DRIVER_UART_RETRY_DELAY_MS);
  }

  Serial.print(F("TMC "));Serial.print(motor.face);Serial.print(F(" / UART: connection="));
  Serial.print(connection);Serial.print(F(", version=0x"));
  if(version<0x10) Serial.print('0');Serial.print(version,HEX);
  Serial.print(F(", Versuche="));Serial.println(usedAttempts);
  if(connection!=0 || version!=0x21) return false;

  // Der TMC2209 startet normalerweise mit 256 Mikroschritten. Erzwinge, dass
  // MRES aus dem UART-Register und nicht aus den Konfigurationspins kommt.
  // Ohne diese beiden Bits kann microsteps(2) wirkungslos bleiben.
  driver.pdn_disable(true);
  driver.mstep_reg_select(true);
  driver.toff(5);
  // Die BTT-Treiber kommen ab Werk mit analoger VREF-Stromskalierung. Fuer
  // einen wirksamen per UART gesetzten Strom muss die interne Referenz aktiv
  // sein; die externen 0,110-Ohm-Messwiderstaende bleiben in Benutzung.
  driver.I_scale_analog(false);
  driver.internal_Rsense(false);
  driver.rms_current(MOTOR_RMS_CURRENT_MA,MOTOR_HOLD_MULTIPLIER);
  driver.microsteps(DRIVER_MICROSTEPS);
  driver.intpol(true);
  driver.en_spreadCycle(USE_SPREADCYCLE);
  driver.pwm_autoscale(true);
  // Alle Schattenregister noch einmal gemeinsam schreiben. Das verhindert,
  // dass eine einzelne verlorene Software-UART-Uebertragung MRES auf 256
  // stehen laesst.
  driver.push();
  delay(10);

  uint16_t configuredMicrosteps=driver.microsteps();
  bool registerSelection=driver.mstep_reg_select();
  for(uint8_t attempt=1;
      attempt<DRIVER_UART_ATTEMPTS &&
      (configuredMicrosteps!=DRIVER_MICROSTEPS || !registerSelection);
      ++attempt) {
    driver.pdn_disable(true);
    driver.mstep_reg_select(true);
    driver.microsteps(DRIVER_MICROSTEPS);
    driver.intpol(true);
    delay(DRIVER_UART_RETRY_DELAY_MS);
    configuredMicrosteps=driver.microsteps();
    registerSelection=driver.mstep_reg_select();
  }

  Serial.print(F("TMC "));Serial.print(motor.face);
  Serial.print(F(" eingestellt: Strom="));Serial.print(driver.rms_current());
  Serial.print(F("mA, Mikroschritte="));Serial.print(configuredMicrosteps);
  Serial.print(F(", UART-MSTEP="));Serial.println(registerSelection ? F("JA") : F("NEIN"));
  if(configuredMicrosteps!=DRIVER_MICROSTEPS || !registerSelection) {
    Serial.print(F("FEHLER: TMC "));Serial.print(motor.face);
    Serial.println(F(" hat die Mikroschritt-Einstellung nicht uebernommen."));
    return false;
  }
  return true;
}

static bool configureAllDrivers() {
  failedDriverFaces[0]='\0';
  bool success=true;
  for(MotorConfig &motor:motors) {
    if(!configureDriver(motor)) {
      success=false;
      const size_t length=strlen(failedDriverFaces);
      if(length+1<sizeof(failedDriverFaces)) {
        failedDriverFaces[length]=motor.face;
        failedDriverFaces[length+1]='\0';
      }
    }
  }
  return success;
}

static void sendDriverError(uint32_t jobId) {
  Serial1.print(F("ERR "));Serial1.print(jobId);Serial1.print(F(" DRIVER_UART_"));
  Serial1.println(failedDriverFaces[0] ? failedDriverFaces : "UNKNOWN");
}

static void setDriversEnabled(bool enabled) {
  for(const MotorConfig &motor:motors) digitalWrite(motor.enablePin,enabled ? LOW : HIGH);
}

static int8_t findMotor(char face) {
  for(uint8_t i=0;i<sizeof(motors)/sizeof(motors[0]);++i)
    if(motors[i].face==face) return (int8_t)i;
  return -1;
}

static void checkEmergencyStop() {
  while(Serial1.available()) if(Serial1.read()=='!') abortRequested=true;
  while(Serial.available()) {
    const char c=(char)Serial.read();
    if(c=='!' || c=='x' || c=='X') abortRequested=true;
  }
}

static uint16_t pulseHalfPeriodUs(uint32_t pulse,uint32_t total,bool scramble,bool halfTurn) {
  if(scramble) return SCRAMBLE_HALF_PERIOD_US;
  uint32_t ramp=halfTurn ? ACCELERATION_180_STEPS : ACCELERATION_STEPS;
  if(ramp>total/2) ramp=total/2;
  uint32_t position=pulse;
  if(total-1-pulse<position) position=total-1-pulse;
  const uint16_t fastHalfPeriod=halfTurn ? FAST_180_HALF_PERIOD_US : FAST_HALF_PERIOD_US;
  if(position>=ramp || ramp==0) return fastHalfPeriod;
  const uint32_t difference=SLOW_HALF_PERIOD_US-fastHalfPeriod;
  return (uint16_t)(SLOW_HALF_PERIOD_US-(difference*position/ramp));
}

static inline void writeTimerStep(TimerTurn &turn,bool high) {
  if(high) *turn.stepPort|=turn.stepMask;
  else *turn.stepPort&=(uint8_t)~turn.stepMask;
}

static void setupMotionTimer() {
  noInterrupts();
  TCCR1A=0;
  TCCR1B=_BV(CS11); // Timer1 frei laufend, Prescaler 8: 0,5 us pro Tick bei 16 MHz.
  TIMSK1&=(uint8_t)~_BV(OCIE1A);
  TIFR1=_BV(OCF1A);
  interrupts();
}

static void prepareTimerTurn(TimerTurn &turn,const ParsedMove &move,bool scramble) {
  turn.motor=&motors[move.motorIndex];
  turn.stepPort=portOutputRegister(digitalPinToPort(turn.motor->stepPin));
  turn.stepMask=digitalPinToBitMask(turn.motor->stepPin);
  turn.pulses=(uint32_t)turn.motor->quarterSteps*move.quarterTurns;
  turn.completedPulses=0;
  turn.nextEdgeTicks=0;
  turn.scramble=scramble;
  turn.halfTurn=move.quarterTurns==2;
  turn.halfPeriodTicks=(uint16_t)(pulseHalfPeriodUs(
    0,turn.pulses,turn.scramble,turn.halfTurn)*TIMER1_TICKS_PER_US);
  turn.stepHigh=false;
  turn.finished=false;
  writeTimerStep(turn,false);
}

ISR(TIMER1_COMPA_vect) {
  const uint16_t now=TCNT1;
  for(uint8_t i=0;i<timerTurnCount;++i) {
    TimerTurn &turn=timerTurns[i];
    if(turn.finished || (int16_t)(now-turn.nextEdgeTicks)<0) continue;

    if(!turn.stepHigh) {
      writeTimerStep(turn,true);
      turn.stepHigh=true;
      turn.nextEdgeTicks+=(uint16_t)turn.halfPeriodTicks;
    } else {
      writeTimerStep(turn,false);
      turn.stepHigh=false;
      if(++turn.completedPulses>=turn.pulses) {
        turn.finished=true;
      } else {
        turn.halfPeriodTicks=(uint16_t)(pulseHalfPeriodUs(
          turn.completedPulses,turn.pulses,turn.scramble,turn.halfTurn)*TIMER1_TICKS_PER_US);
        turn.nextEdgeTicks+=(uint16_t)turn.halfPeriodTicks;
      }
    }
  }

  const uint16_t scheduleNow=TCNT1;
  uint16_t nearestDelta=0x7fff;
  bool pending=false;
  for(uint8_t i=0;i<timerTurnCount;++i) {
    TimerTurn &turn=timerTurns[i];
    if(turn.finished) continue;
    int16_t delta=(int16_t)(turn.nextEdgeTicks-scheduleNow);
    if(delta<(int16_t)TIMER1_MIN_LEAD_TICKS) {
      turn.nextEdgeTicks=(uint16_t)(scheduleNow+TIMER1_MIN_LEAD_TICKS);
      delta=TIMER1_MIN_LEAD_TICKS;
    }
    if((uint16_t)delta<nearestDelta) nearestDelta=(uint16_t)delta;
    pending=true;
  }

  if(pending) {
    OCR1A=(uint16_t)(scheduleNow+nearestDelta);
  } else {
    TIMSK1&=(uint8_t)~_BV(OCIE1A);
    timerMotionActive=false;
  }
}

static void stopTimerMotion() {
  noInterrupts();
  TIMSK1&=(uint8_t)~_BV(OCIE1A);
  for(uint8_t i=0;i<timerTurnCount;++i) {
    writeTimerStep(timerTurns[i],false);
    timerTurns[i].stepHigh=false;
    timerTurns[i].finished=true;
  }
  timerMotionActive=false;
  interrupts();
}

static bool areOppositeFaces(const ParsedMove &first,const ParsedMove &second) {
  const char a=motors[first.motorIndex].face;
  const char b=motors[second.motorIndex].face;
  return (a=='U' && b=='D') || (a=='D' && b=='U') ||
         (a=='R' && b=='L') || (a=='L' && b=='R') ||
         (a=='F' && b=='B') || (a=='B' && b=='F');
}

static bool runTimerMotion(const ParsedMove &first,const ParsedMove *second,bool scramble) {
  MotorConfig &firstMotor=motors[first.motorIndex];
  digitalWrite(firstMotor.dirPin,
               (first.inverse ? !firstMotor.clockwiseDirHigh : firstMotor.clockwiseDirHigh) ? HIGH : LOW);
  if(second) {
    MotorConfig &secondMotor=motors[second->motorIndex];
    digitalWrite(secondMotor.dirPin,
                 (second->inverse ? !secondMotor.clockwiseDirHigh : secondMotor.clockwiseDirHigh) ? HIGH : LOW);
  }
  delayMicroseconds(20);

  noInterrupts();
  timerTurnCount=second ? 2 : 1;
  prepareTimerTurn(timerTurns[0],first,scramble);
  if(second) prepareTimerTurn(timerTurns[1],*second,scramble);
  const uint16_t startsAt=(uint16_t)(TCNT1+TIMER1_MIN_LEAD_TICKS);
  for(uint8_t i=0;i<timerTurnCount;++i) timerTurns[i].nextEdgeTicks=startsAt;
  timerMotionActive=true;
  OCR1A=startsAt;
  TIFR1=_BV(OCF1A);
  TIMSK1|=_BV(OCIE1A);
  interrupts();

  uint32_t lastEmergencyPoll=micros();
  while(timerMotionActive) {
    const uint32_t now=micros();
    if(now-lastEmergencyPoll>=EMERGENCY_POLL_US) {
      lastEmergencyPoll=now;
      checkEmergencyStop();
      if(abortRequested) {
        stopTimerMotion();
        return false;
      }
    }
  }
  return true;
}

static bool turnMotor(const ParsedMove &move,bool scramble) {
  const uint32_t turnStartedAt=micros();
  const bool success=runTimerMotion(move,nullptr,scramble);
  if(MOTION_DEBUG && success) {
    Serial.print(F("Drehzeit "));Serial.print(motors[move.motorIndex].face);
    if(move.quarterTurns==2) Serial.print('2');
    else if(move.inverse) Serial.print('\'');
    Serial.print(F(": "));Serial.print((micros()-turnStartedAt)/1000UL);Serial.println(F(" ms"));
  }
  return success;
}

static bool turnMotorPair(const ParsedMove &first,const ParsedMove &second,bool scramble) {
  const uint32_t turnStartedAt=micros();
  const bool success=runTimerMotion(first,&second,scramble);
  if(MOTION_DEBUG && success) {
    Serial.print(F("Parallele Drehzeit "));Serial.print(motors[first.motorIndex].face);
    Serial.print('+');Serial.print(motors[second.motorIndex].face);Serial.print(F(": "));
    Serial.print((micros()-turnStartedAt)/1000UL);Serial.println(F(" ms"));
  }
  return success;
}

static bool parseMoves(char *text,ParsedMove *parsed,size_t &count) {
  count=0;
  char *save=nullptr;
  for(char *token=strtok_r(text," ",&save);token;token=strtok_r(nullptr," ",&save)) {
    if(count>=MAX_MOVES) return false;
    const int8_t index=findMotor(token[0]);
    if(index<0) return false;
    ParsedMove move={(uint8_t)index,1,false};
    if(token[1]=='\0') {}
    else if(token[1]=='\'' && token[2]=='\0') move.inverse=true;
    else if(token[1]=='2' && token[2]=='\0') move.quarterTurns=2;
    else return false;
    parsed[count++]=move;
  }
  return count>0;
}

static void executeRun(uint32_t jobId,char *moveText,bool scramble) {
  if(!MOTION_CONFIGURATION_CONFIRMED) {
    Serial1.print(F("ERR "));Serial1.print(jobId);Serial1.println(F(" CONFIG_REQUIRED"));
    return;
  }
  if(!driversReady) {
    sendDriverError(jobId);
    return;
  }
  if(running) {
    Serial1.print(F("ERR "));Serial1.print(jobId);Serial1.println(F(" BUSY"));
    return;
  }

  ParsedMove parsed[MAX_MOVES];
  size_t moveCount=0;
  if(!parseMoves(moveText,parsed,moveCount)) {
    Serial1.print(F("ERR "));Serial1.print(jobId);Serial1.println(F(" BAD_MOVES"));
    return;
  }

  running=true;abortRequested=false;
  setDriversEnabled(true);delay(DRIVER_ENABLE_DELAY_MS);
  Serial1.print(F("START "));Serial1.print(jobId);Serial1.print(' ');Serial1.println(moveCount);
  const uint32_t startedAt=millis();
  if(MOTION_DEBUG) {
    if(scramble) {
      Serial.print(F("Feste Scramble-Geschwindigkeit: "));
      Serial.print(SCRAMBLE_SPEED_DEG_PER_SEC);Serial.println(F(" Grad/s"));
    } else {
      Serial.print(F("Loese-Geschwindigkeit bis: "));
      Serial.print(MAX_SPEED_DEG_PER_SEC);Serial.print('/');
      Serial.print(MAX_SPEED_180_DEG_PER_SEC);Serial.println(F(" Grad/s (90/180)"));
    }
  }

  size_t completed=0;
  while(completed<moveCount) {
    const bool parallel=completed+1<moveCount && areOppositeFaces(parsed[completed],parsed[completed+1]);
    const bool success=parallel ? turnMotorPair(parsed[completed],parsed[completed+1],scramble)
                                : turnMotor(parsed[completed],scramble);
    if(!success) break;
    completed+=parallel ? 2 : 1;
    Serial1.print(F("MOVE "));Serial1.print(jobId);Serial1.print(' ');
    Serial1.print(completed);Serial1.print(' ');Serial1.println(moveCount);
  }

  setDriversEnabled(false);running=false;
  if(abortRequested) {
    Serial1.print(F("ERR "));Serial1.print(jobId);Serial1.println(F(" ABORTED"));
  } else {
    Serial1.print(F("DONE "));Serial1.print(jobId);Serial1.print(' ');Serial1.println(millis()-startedAt);
  }
}

static void handleLine(char *line) {
  while(*line==' ') ++line;
  if(!strcmp(line,"PING")) {
    if(driversReady) Serial1.println(F("PONG"));
    else sendDriverError(0);
    return;
  }
  if(!strcmp(line,"!")) { abortRequested=true;return; }
  bool scramble=false;
  char *idText=nullptr;
  if(!strncmp(line,"RUN ",4)) idText=line+4;
  else if(!strncmp(line,"SCRAMBLE ",9)) {scramble=true;idText=line+9;}
  else {Serial1.println(F("ERR 0 BAD_COMMAND"));return;}

  char *separator=strchr(idText,' ');
  if(!separator) { Serial1.println(F("ERR 0 BAD_RUN"));return; }
  *separator='\0';
  const uint32_t jobId=strtoul(idText,nullptr,10);
  if(jobId==0) { Serial1.println(F("ERR 0 BAD_ID"));return; }
  executeRun(jobId,separator+1,scramble);
}
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
void loop() {
  if(!driversReady && millis()-lastDriverRetry>=3000) {
    lastDriverRetry=millis();
    Serial.println(F("TMC-UART wird erneut geprueft..."));
    driversReady=configureAllDrivers();
    if(driversReady) {
      Serial.println(F("TMC-Konfiguration: ALLE BEREIT"));
      Serial1.println(F("READY"));
    } else {
      Serial.print(F("TMC-UART fehlt bei: "));Serial.println(failedDriverFaces);
    }
  }
  while(Serial1.available()) {
    const char c=(char)Serial1.read();
    if(c=='!') { abortRequested=true;continue; }
    if(c=='\r') continue;
    if(c=='\n') {
      receiveLine[receiveLength]='\0';
      handleLine(receiveLine);
      receiveLength=0;
    } else if(receiveLength+1<sizeof(receiveLine)) {
      receiveLine[receiveLength++]=c;
    } else {
      receiveLength=0;
      Serial1.println(F("ERR 0 LINE_TOO_LONG"));
    }
  }
}

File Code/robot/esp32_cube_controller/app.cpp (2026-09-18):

#include <Arduino.h>
#include <BLEDevice.h>
#include <BLEUtils.h>
#include <BLEScan.h>
#include <mbedtls/aes.h>
#include <LiquidCrystal.h>
#include <atomic>
#include "qiyi_protocol.h"
#include "solver_adapter.h"

// Bluetooth address of this robot's QiYi QYSC-S.
static const char CUBE_MAC[]="CC:A3:00:00:EB:66";
static const char BUILD_TAG[]="ROBOT-ESP-2026-09-17-3";
// LCD1602 in 4-bit mode: RS, E, D4, D5, D6, D7.
static LiquidCrystal lcd(1,2,40,41,42,21);
static bool lcdReady=false;
static bool lcdWiringMode=false;
// Separate hardware UART to the F6. USB Serial remains the PC monitor.
static HardwareSerial f6Serial(1);
static constexpr uint8_t F6_RX_PIN=44; // ESP pin marked RX; from F6 TX1 through divider
static constexpr uint8_t F6_TX_PIN=43; // ESP pin marked TX; directly to F6 RX1
static constexpr uint32_t F6_BAUD=250000;
static constexpr uint8_t START_BUTTON_PIN=0; // On-board BOOT button, active LOW
static BLEUUID serviceUUID("0000fff0-0000-1000-8000-00805f9b34fb");
static BLEUUID characteristicUUID("0000fff6-0000-1000-8000-00805f9b34fb");
struct Packet { uint16_t length; uint8_t bytes[256]; };
struct Job { cube_t cube; uint32_t generation; bool demo; };
struct Result { uint32_t generation,ms; bool demo,ok; int moves; char text[128]; };
enum class MotionGoal:uint8_t { SOLVE, SCRAMBLE };
static QueueHandle_t packets,jobs,results;
static std::atomic<bool> ready(false),busy(false),lost(false),overflow(false);
static BLEClient* client=nullptr;
static BLERemoteCharacteristic* characteristic=nullptr;
static BLEAdvertisedDevice* candidate=nullptr;
static uint8_t hardwareMac[6];
static bool online=false,haveState=false,haveTimestamp=false;
static cube_t current;
static uint32_t generation=0,lastTimestamp=0,helloAt=0,lastScan=0;
static int battery=-1;
static bool f6Ready=false,motionActive=false,motionPending=false,finalResultVisible=false;
static bool cubeVerificationPending=false;
static bool calibrationAwaitingState=false;
static uint32_t f6LastSeen=0,f6LastPing=0,motionStartedAt=0,nextJobId=1,activeJobId=0;
static uint32_t cubeVerificationDeadline=0,completedMotionMs=0,motionGenerationAtStart=0;
static uint32_t lastSolverMs=0;
static uint16_t motionDone=0,motionTotal=0;
static MotionGoal motionGoal=MotionGoal::SOLVE;
static char f6Line[192];
static size_t f6LineLength=0;
static bool buttonRaw=HIGH,buttonStable=HIGH;
static uint32_t buttonChangedAt=0;
static uint32_t buttonPressedAt=0;
static bool buttonLongHandled=false;
static constexpr uint32_t CALIBRATION_HOLD_MS=3000;

static void lcdLine(uint8_t row,const char* text) {
    if(!lcdReady || lcdWiringMode) return;
    char line[17];
    size_t n=strlen(text);if(n>16) n=16;
    memcpy(line,text,n);memset(line+n,' ',16-n);line[16]=0;
    lcd.setCursor(0,row);lcd.print(line);
}

static void lcdMessage(const char* first,const char* second) {
    lcdLine(0,first);lcdLine(1,second);
}

static void lcdTest() {
    lcdWiringMode=false;
    // Das LCD kann spaeter als der ESP mit Strom versorgt werden. Deshalb beim
    // manuellen Test erneut initialisieren und nicht nur neuen Text senden.
    lcd.begin(16,2);
    delay(50);
    lcd.clear();
    lcdMessage("LCD TEST OK","1234567890123456");
    Serial.println("LCD neu initialisiert; Testtext gesendet.");
}

static void lcdWiringTest() {
    static const uint8_t gpioPins[]={1,2,40,41,42,21};
    static const uint8_t lcdPins[]={4,6,11,12,13,14};
    lcdWiringMode=true;
    for(uint8_t pin:gpioPins) {
        pinMode(pin,OUTPUT);
        digitalWrite(pin,LOW);
    }
    Serial.println("LCD-Kabeltest startet in 3 Sekunden. Schwarze Messspitze an LCD 1 (GND).");
    Serial.println("Jeweils nur der angesagte LCD-Pin darf dabei etwa 3,3 V haben.");
    delay(3000);
    for(size_t i=0;i<sizeof(gpioPins);i++) {
        Serial.printf("10 Sekunden: LCD-Pin %u muss etwa 3,3 V haben; alle anderen Signalpins 0 V.\n",lcdPins[i]);
        digitalWrite(gpioPins[i],HIGH);
        delay(10000);
        digitalWrite(gpioPins[i],LOW);
    }
    Serial.println("LCD-Kabeltest beendet; LCD wird neu initialisiert.");
    lcdTest();
}

static void showMotionTime() {
    if(!motionActive) return;
    const uint32_t elapsed=millis()-motionStartedAt;
    char first[17],second[17];
    snprintf(first,sizeof(first),motionGoal==MotionGoal::SCRAMBLE ? "Mischt: %u/%u" : "Loest: %u/%u",motionDone,motionTotal);
    snprintf(second,sizeof(second),"Zeit: %lu.%03lus",(unsigned long)(elapsed/1000),(unsigned long)(elapsed%1000));
    lcdMessage(first,second);
}

static void showCompletedMotionTime(const char* status) {
    char second[17];
    snprintf(second,sizeof(second),"Zeit: %lu.%03lus",
             (unsigned long)(completedMotionMs/1000),(unsigned long)(completedMotionMs%1000));
    lcdMessage(status,second);
}
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
